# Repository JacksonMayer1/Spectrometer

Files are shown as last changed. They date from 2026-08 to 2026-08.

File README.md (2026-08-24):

# Raspberry Pi 3D-Printed Spectrometer

## Overview

I created a 3D-printed spectrometer using readily available components and a Bambu A1 printer. The spectrometer uses a 1,000 lines/mm diffraction grating to spatially separate incoming light by wavelength, a Raspberry Pi Camera Module 3 to capture the spectrum, a 15–22 pin FFC cable, and a Raspberry Pi 5 to process the data and display the spectrum graphically.

While this spectrometer operates in the visible light range (400–700nm) and cannot directly measure pollutant concentrations, it can detect the optical signature of wildfire smoke in the solar spectrum. Fine aerosol particles scatter blue wavelengths more than red, producing a measurable spectral shift during smoke events that reflects the same differential wavelength scattering principles used by professional atmospheric instruments. During Southern California fire season, this instrument will be pointed at the sky through a white paper diffuser to capture solar spectra. These readings will be compared against clear-day baseline measurements taken earlier in the year to gauge pollution levels during fire season.

---

## Video

[https://youtu.be/KasW3qDfX2g](https://youtu.be/KasW3qDfX2g)

---

## Features

- Design the optical enclosure using Shapr3D computer-aided design (CAD) software
- Export the STL file and print using a Bambu A1 3D printer
- Add two razors to narrow and more sharply define the slit that captures light
- Use a diffraction grating to separate light into its component wavelengths
- Capture the dispersed spectrum using a Raspberry Pi Camera Module 3
- Process the camera data using a Raspberry Pi 5
- Convert the captured spectrum into a graphical representation of intensity as a function of wavelength
- Calibrate the instrument using light sources with known wavelength values

---

## Main Optical Design

The design is made up of two components.

### Primary Component — Main Cylindrical Enclosure

A long cylindrical enclosure with the following features:

- Narrow entrance slit at bottom end: 2×10mm
- Angled opening at the top end
- Bottom end cover: 1mm thick, 40mm in diameter
- Angled opening at top: 33° relative to bottom surface
- Body height: 130mm at lowest point, 153mm at highest point (not including bottom end cover)
- Body outer diameter: 40mm; inner diameter: 36mm
- Angled opening at top creates an elliptical interface rather than a circular one

### Secondary Component — Elliptical Camera Assembly

A shorter cylinder with the following features:

- Base matches the elliptical face on the top of the primary component
- Base is open and sits on the angled top of the primary component, over the diffraction grating
- Height: 15mm (not including top cover)
- Top cover: 1mm thick, closed except for a 10.5mm diameter circular opening centered on the ellipse

### Dimensional Math

The dimensions of the spectrometer were determined using the grating equation for light hitting normal (90°) to the grating surface:

```
d · sin θ = m · λ
```

Where:

- `m` = Spectral order = 1 (first-order rainbow)
- `λ` = Wavelength = 550nm (green/yellow, center of visible spectrum)
- `d` = Line spacing (grating period)

**Step 1 — Calculate d (spacing between grating lines)**

The grating has 1,000 lines/mm:

```
d = 1mm / 1000 = 0.001mm = 1000nm
```

**Step 2 — Solve for θ₁ (first-order diffraction angle)**

```
sin θ₁ = (m · λ) / d = (1 · 550nm) / 1000nm = 0.55

θ₁ = arcsin(0.55) = 33.37°
```

---

## 3D Printing

Use Shapr3D or another CAD application to design the enclosure. Export as an STL file and print using a 3D printer. Black PLA filament is optimal to reduce stray light and internal reflections. The CAD/STL files are included in this repository so the design can be reproduced.

---

## Razors

Attach two single-edge razor blades to the slit at the bottom of the main cylinder to create a narrow, precise opening for a sharper spectrum. Place the razors over the slit facing each other, 1mm apart, and secure using black duct tape.

---

## Diffraction Grating

Place the diffraction grating at the angled end of the main cylinder and secure using black duct tape.

Orient the grating so that its glass surface faces inward toward the entrance slit and the diffracted side faces outward toward the camera assembly.

To determine the line direction of the grating, hold it up to a light source — the rainbow spectrum spreads perpendicular to the direction of the lines. Orient the grating so that its lines are parallel to the slit at the base of the cylinder.

When light enters through the slit, it travels through the main optical chamber and strikes the diffraction grating. The grating separates the incoming light into its component wavelengths, which appear at different positions across the camera's field of view.

---

## Camera Module

Use a Raspberry Pi Camera Module 3 as the optical detector. Enclose the module in an ABS Housing IMX519 16MP 25×24mm camera board case.

Secure the two 3D-printed components together using black duct tape. Attach the camera module within its case to the elliptical cylinder component using black duct tape. Orient the lens so that it is positioned directly over the circular opening of the elliptical cylinder. The camera lens sits 15mm above the diffraction grating and receives the light dispersed by the grating.

---

## Computational Platform

Connect the Camera Module 3 to a Raspberry Pi 5 using the camera's 15–22 pin FFC cable.

The Raspberry Pi 5 will:

- Capture images from the camera
- Process the image data
- Calibrate pixel position to wavelength
- Generate a graphical representation of intensity vs. wavelength

---

## Installation

```bash
# ============================================================
# Install PySpectrometer2
# Original software by Les Wright (leswright1977)
# https://github.com/leswright1977/PySpectrometer2
# Licensed under GNU GPL v3.0
# ============================================================

# 1. Clone the repository
git clone https://github.com/leswright1977/PySpectrometer2
cd PySpectrometer2

# 2. Install dependencies the correct way for Pi OS Bookworm
#    (do NOT use pip for opencv — use apt to avoid conflicts
#    with the system Picamera2 installation)
sudo apt-get update
sudo apt-get install -y python3-opencv python3-picamera2 python3-scipy python3-numpy

# 3. Install peakutils (not available via apt on Bookworm)
pip3 install peakutils --break-system-packages

# 4. Navigate to the src directory where the scripts live
#    (note: scripts are NOT in the root directory)
cd src

# 5. Make the Picamera2 version executable
chmod +x PySpectrometer2-Picam2-v1.0.py

# 6. Verify the Camera Module 3 is detected before running
#    (if no camera appears, check ribbon cable orientation —
#    contacts face toward USB ports on Pi 5)
libcamera-hello --list-cameras

# 7. Launch the spectrometer
./PySpectrometer2-Picam2-v1.0.py

# ============================================================
# EXPECTED RESULT:
# A window opens showing:
#   TOP PANEL    — live camera feed with sampling line
#   BOTTOM PANEL — real-time wavelength vs intensity graph
#
# If the window does not open, check that your Pi is connected
# to a monitor. PySpectrometer2 requires a display to run.
# SSH alone is insufficient — use SSH with X11 forwarding or
# run directly from the Pi desktop.
# ============================================================
```

---

## Calibration

Red and green XIMIBI laser pens with known wavelengths were initially used to calibrate the instrument by establishing a relationship between camera pixel position and wavelength. The laser pointers were reflected off cardboard placed approximately 25mm from the slit. Neither produced sufficient signal for reliable peak detection — diffuse reflection off the cardboard surface reduced intensity to levels too low for the camera to detect a clean spectral peak.

A broadband white flashlight was then tested by shining it at a piece of cardboard placed approximately 25mm from the slit. This produced a strong, stable spectrum across the full visible range (400–700nm), and known wavelength values were entered at reference peaks in the software. However, while the top panel showed a single clean spectrum, this calibration attempt yielded multiple repeated spectra in the graphical representation in the bottom panel.

The default calibration built into PySpectrometer2 was then applied without manual adjustment. This correctly bounded the x-axis to the visible wavelength range (approximately 400–700nm), eliminated the repeated spectra artifact in the bottom panel, and produced a single clean wavelength-intensity curve aligned closely with expected reference wavelengths.

---

## Project Structure

```
README.md
shapr3d_export_2026-08-16_17h39m.stl
images/
    3DPrinting.jpeg
    Slit.jpg
    CameraModule.jpg
    FullSpectrometer.jpg
    Blue_Light.jpg
```

---

## Images

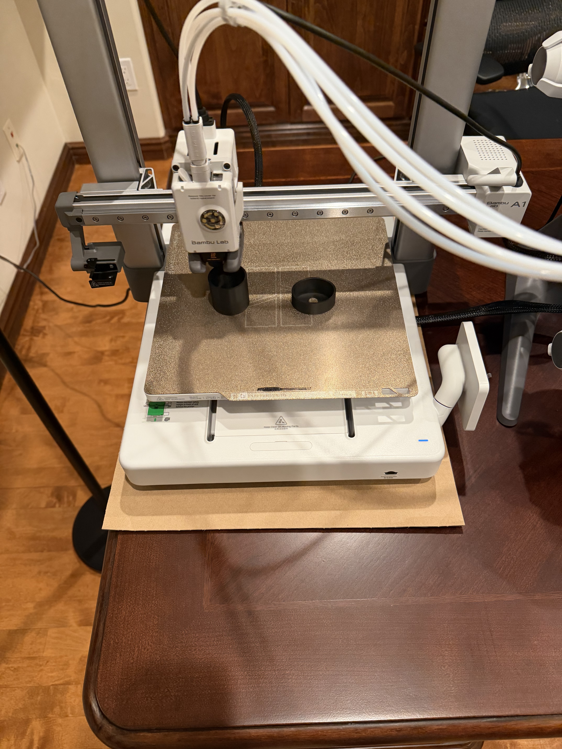
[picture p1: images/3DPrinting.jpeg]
3D Printing

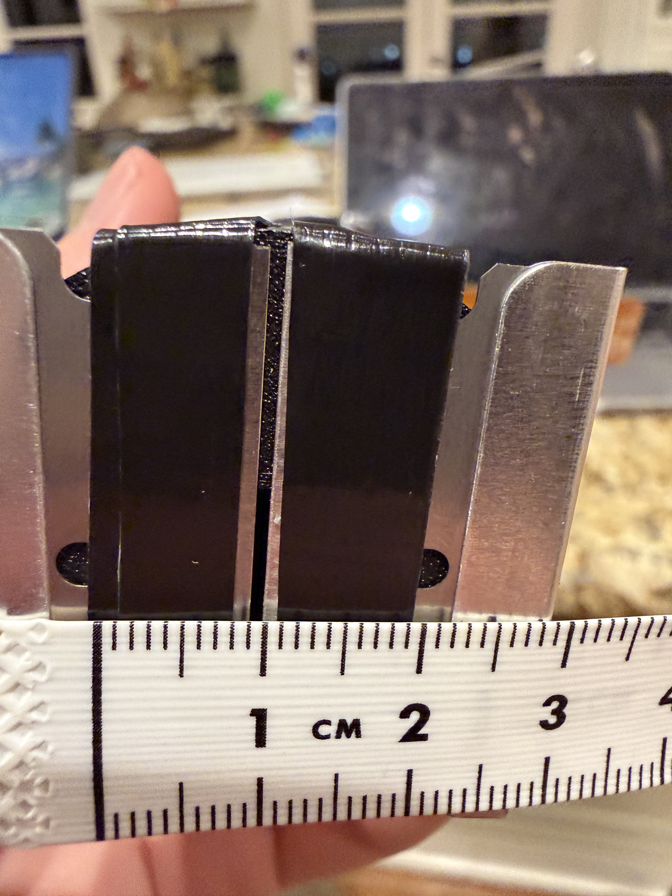
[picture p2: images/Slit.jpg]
Slit

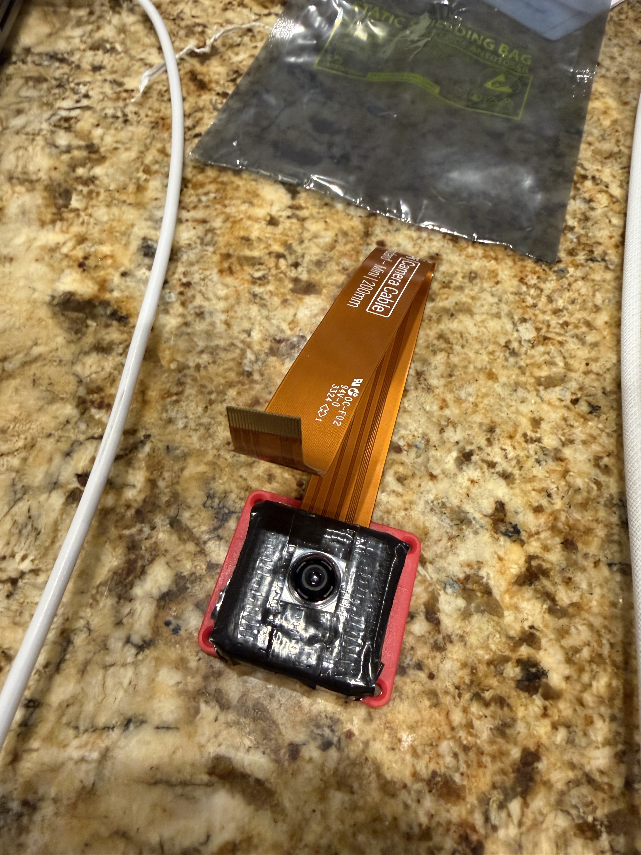
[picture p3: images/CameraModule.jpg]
Camera Module

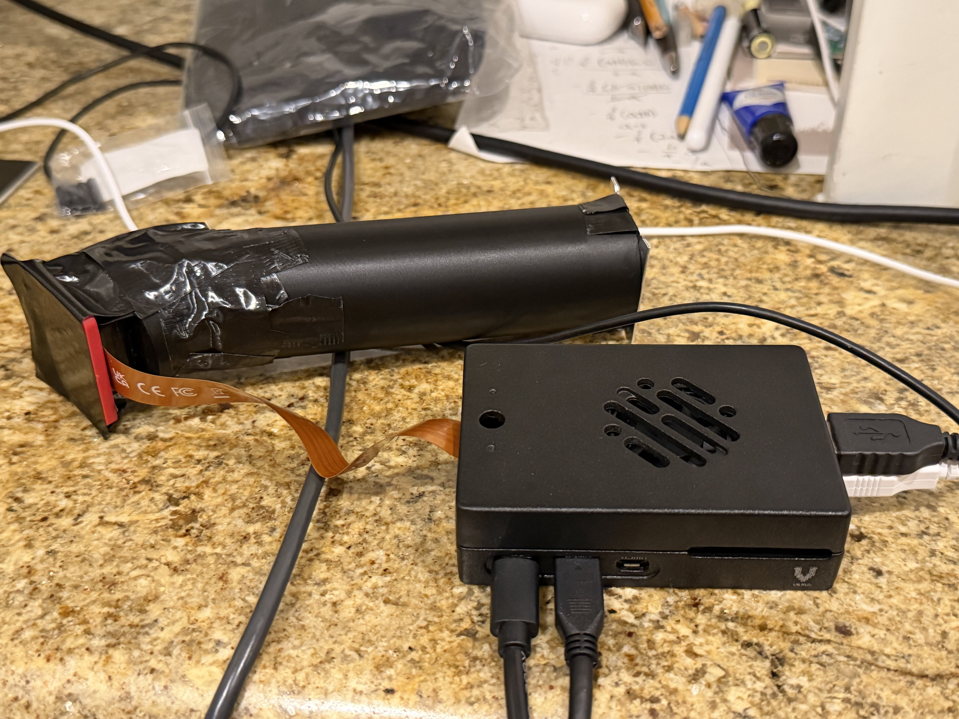
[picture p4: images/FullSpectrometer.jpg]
Full Spectrometer

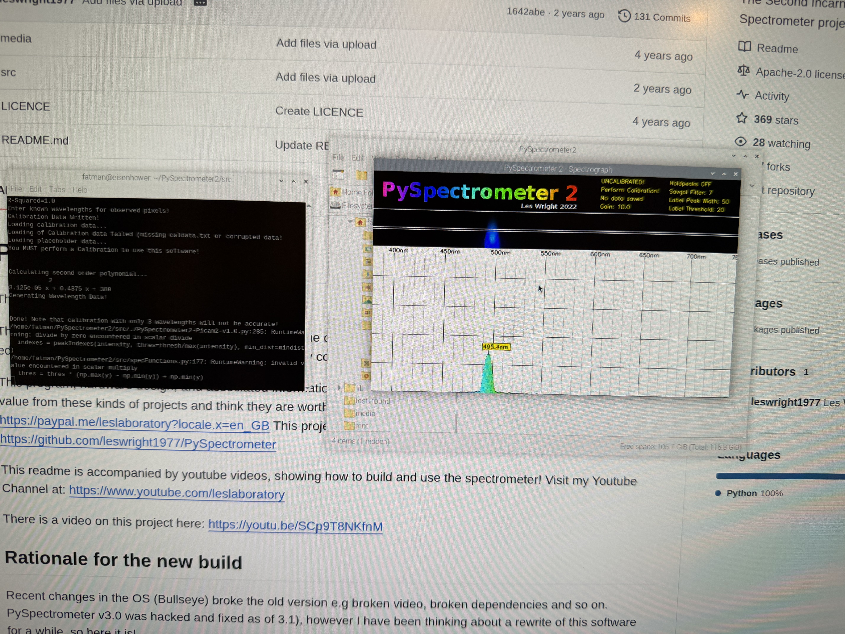
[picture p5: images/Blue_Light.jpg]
Blue Light


---

## Author

Jackson Mayer — [jacksonmayer1](https://github.com/jacksonmayer1)

---

## License

This project is licensed under the MIT License — see the [LICENSE](LICENSE) file for details.

The software used in this project is not original work and is not covered by this license. See the Acknowledgements section below for the applicable license.

---

## Acknowledgements

Spectrometer software based on PySpectrometer2
by Les Wright (leswright1977)
[https://github.com/leswright1977/PySpectrometer2](https://github.com/leswright1977/PySpectrometer2)
Licensed under GNU GPL v3.0

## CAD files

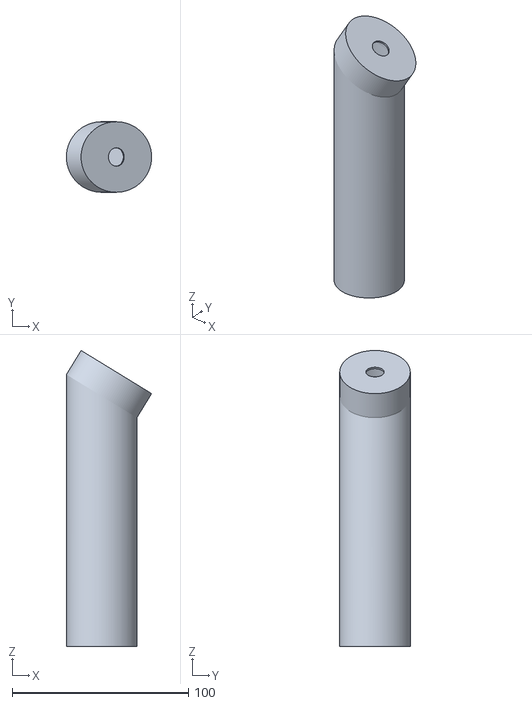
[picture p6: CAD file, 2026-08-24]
shapr3d_export_2026-08-16_17h39m.stl
48.3 x 40.0 x 167.9
